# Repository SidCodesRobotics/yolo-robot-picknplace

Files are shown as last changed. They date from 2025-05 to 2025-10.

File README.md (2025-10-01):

# YOLOv8-Guided Mobile Robot with 5DOF Arm for Autonomous Waste Sorting 🤖






> 🎓 Final year project implementing an autonomous waste sorting robot using computer vision and robotics.

<p align="center">
MegaPi
</p>

## 📝 Table of Contents
- [About](#about)
- [Features](#features)
- [Architecture](#architecture)
- [Getting Started](#getting-started)
- [Current Limitations](#current-limitations)
- [Roadmap](#roadmap)
- [Contributing](#contributing)
- [Authors](#authors)
- [Acknowledgments](#acknowledgments)
- [License](#license)

## 🤔 About 

This project implements an autonomous waste sorting robot that combines computer vision, robotics, and machine learning. Using a YOLOv8n model for waste detection and ArUco markers for bin identification, the robot can identify, collect, and sort different types of waste materials.

📄 Our research paper can be found here: [Link to be added later]

### 🎯 Key Features 

- 🤖 Autonomous waste detection and sorting
- 🧠 Custom-trained YOLOv8n model (0.941 mAP@50)
- 🦾 5-DOF robotic arm for precise manipulation
- 🎯 ArUco marker-based bin detection
- 📱 Android app for remote control
- 🎛️ Dual microcontroller architecture
- 🔄 Real-time object detection

## 🏗️ Architecture 

### Hardware Stack
```
Robot/
│
├── Brain/
│   ├── Raspberry Pi 4 (8GB)
│   └── Arduino Mega 2560
│
├── Sensors/
│   ├── RPi Camera v2
│   ├── HC-SR04 Ultrasonic
│   └── HC-05 Bluetooth
│
├── Actuators/
│   ├── 3x MG996R Servos
│   ├── 3x SG90 Servos
│   └── 4x TT DC Motors
│
└── Controllers/
    ├── PCA9685 PWM Driver
    └── L293D Motor Driver
```

### Software Stack
```
Software/
│
├── Vision/
│   ├── YOLOv8n Custom Model
│   └── OpenCV (ArUco + Image Processing)
│
├── Control/
│   ├── Python High-level Control
│   └── Arduino C++ Low-level Control
│
└── Interface/
    └──  Android App
```

# Autonomous Waste Sorting Robot

## 🚀 Getting Started 

This is a final year project by Haouioui Sid Ahmed and Houhou Mohamed Dhia Eddine, focused on implementing an autonomous waste sorting robot using computer vision and robotics.

Our paper can be found here: [Link to be added]

---

### Hardware Requirements

Before you begin, ensure you have the following main **hardware components**:

* **Raspberry Pi 4 Model B** (8 GB RAM recommended): For computer vision and high-level control.
* **Arduino Mega 2560**: For motor control and low-level actuation tasks.
* **Robotic Arm**: A 5-DOF arm using SG90 and MG996R servo motors.
* **4-Wheeled Mobile Platform**: Driven by TT gear motors.
* **Raspberry Pi Camera Module v2**: Provides visual input for waste detection.
* **HC-SR04 Ultrasonic Sensor**: For distance measurement.
* **HC-05 Bluetooth Module**: For potential remote control and debugging.
* **Power Supply**:
    * A 7.4V 3000mAh LiPo battery pack for the Raspberry Pi.
    * Three 3.7V 2800mAh 18650 batteries for the Arduino and its components.
* **Motor Driver**: L293D Motor Driver Module for DC motors.
* **PWM Driver Board**: PCA9685 for controlling servo motors.
* **UART Connection**: Ensure proper wiring between the **Raspberry Pi (Serial /dev/ttyAMA0)** and **Arduino (Serial3)** for communication.

---

### Software Setup

#### 1. Arduino Code (`arduino_code.txt`)

This code controls the robot's physical movements, arm actuation, and communication with the Raspberry Pi via UART.

**Development Environment**:
Install the **Arduino IDE**.

**Libraries**:
You will need to install the following libraries within the Arduino IDE:
* `Wire.h`: For I2C communication.
* `Adafruit_PWMServoDriver.h`: For controlling the PCA9685 servo driver.
* `AFMotor.h`: For controlling the DC motors via the Adafruit Motor Shield (or L293D-based shield).

**Uploading the Code**:
1.  Open `arduino_code.txt` in the Arduino IDE.
2.  Select "**Arduino Mega 2560**" from `Tools` > `Board`.
3.  Select the correct serial port for your Arduino from `Tools` > `Port`.
4.  Upload the sketch to your Arduino Mega 2560.

#### 2. Raspberry Pi Code (`rpi_code.py`)

This Python script handles computer vision using YOLOv8n, object detection, bin identification, and sends commands to the Arduino.

**Operating System**:
Ensure your Raspberry Pi is running a compatible Linux OS (e.g., **Raspberry Pi OS**).

**Python Environment**:
The code is written in **Python 3**. Make sure Python 3 is installed.

**Libraries**:
Install the necessary Python libraries using pip:

```bash
pip install opencv-python time numpy pyserial imutils picamera2 ultralytics
```

## Project Overview

This project implements an autonomous waste sorting robot that combines computer vision, robotics, and machine learning to identify, collect, and sort different types of waste materials. The robot uses a YOLOv8n model for waste detection and ArUco markers for bin identification, all controlled through a Raspberry Pi 4 and Arduino Mega architecture.

### Key Features

- Autonomous waste detection and sorting
- Custom-trained YOLOv8n model for waste classification
- 5-DOF robotic arm for precise object manipulation
- ArUco marker-based bin detection system
- Android app for remote control and monitoring
- Dual microcontroller architecture (Raspberry Pi 4 + Arduino Mega)
- Real-time object detection and distance sensing

## System Architecture

### Hardware Components

- Raspberry Pi 4 (8GB) for high-level control and vision processing
- Arduino Mega 2560 for low-level hardware control
- Custom 3D printed chassis and robotic arm
- 6 servo motors (3x MG996R, 3x SG90) for arm control
- 4 TT DC motors for mobility
- Raspberry Pi Camera Module v2
- HC-SR04 ultrasonic sensor
- HC-05 Bluetooth module
- PCA9685 PWM driver for servo control
- L293D motor driver for DC motors

### Software Stack

- Custom YOLOv8n model for waste detection
- OpenCV for image processing and ArUco detection
- Python for high-level control
- Arduino C++ for low-level control
- Kotlin/Jetpack Compose for Android app
- Custom state machines for autonomous behavior

## Implementation Details

### Vision System
- Trained on a custom dataset from [Roboflow Universe](https://universe.roboflow.com/ai-project-i3wje/waste-detection-vqkjo/dataset/10)
- Detects three waste categories: metal, plastic, and paper
- Achieves 0.941 mAP@50 accuracy
- Real-time processing on Raspberry Pi 4

### Robotic Arm
The 5-DOF robotic arm is based on the design from [OmArTronics](https://omartronics.com/diy-6-dof-robotic-arm-with-bluetooth-control-design-build-and-program/), modified and optimized for our specific use case. It features:
- 5 degrees of freedom for complex manipulation
- Custom-designed 3D printed components
- Precision servo control through PCA9685
- Pre-programmed movement sequences for reliable operation

### Mobile Application
An Android application (MegaPi APP) provides:
- Manual and autonomous mode control
- Real-time status monitoring
- Speed control in manual mode
- Bluetooth connectivity

## Demonstration

See our robot in action: [YouTube Demo](https://youtu.be/VdJLIz-9X8A)

## ⚠️ Current Limitations 

### Robotic Arm and Manipulation
- [ ] Fixed movement patterns using pre-set positions
- [ ] Limited adaptability to object variations
- [ ] No real-time position feedback

### Locomotion and Chassis
- [ ] No encoder feedback for precise movement
- [ ] Timer-based turning (accuracy issues)

### Perception and Sensing
- [ ] Not that relaiable ultrasonic readings
- [ ] Limited 2D vision (no depth perception)
- [ ] ArUco marker dependency for bin detection
- [ ] Limited field of view (no environment scanning)

### Performance
- [ ] Slow object detection (~1 FPS on RPi4) / not obtimized enough
- [ ] Occasional misclassifications
- [ ] Basic state machine architecture
- [ ] Limited Bluetooth range/speed (HC-05)

### Power Management
- [ ] Dual power source complexity
- [ ] No battery monitoring system
- [ ] No low power handling

## 🛣️ Roadmap 
A roadmap for contributors, students, or hobbyists who may want to extend the system and make it more robust.

# Q&A (Roadmap for Improvements)

This section highlights common questions about the project and outlines possible improvements.  
The goal is not to present a final product, but to provide a roadmap for making the system more robust and capable.

---

### Q1. The robotic arm currently uses pre-set positions. Is this enough?

**A1:**  
Pre-set positions are sufficient for a demo or proof of concept, but they limit flexibility.  
Next steps for improvement include:  
- Adding **inverse kinematics (IK)** so the arm can move to any target position dynamically.  
- Using **servo feedback or smart servos** for better precision.  

This would make the robot better at adapting to objects in different positions.

---

### Q2. The project uses only a 2D Pi Camera. Should we add depth sensing?

**A2:**  
A 2D camera works for testing, but without depth perception the robot has trouble estimating distances.  
Improvements:  
- Add a **depth camera** (e.g., Intel RealSense, Orbbec).  
- Or combine the Pi Camera with **distance sensors**.  

This would enable more accurate 3D localization of objects.

---

### Q3. The YOLOv8 model sometimes misclassifies objects. How can detection be improved?

**A3:**  
Ways to improve detection accuracy:  
- Collect more training data from varied environments.  
- Run the model on faster hardware (Coral TPU, Jetson Nano).  

These steps would make classification more consistent and reliable.

---

### Q4. Bin detection relies on ArUco markers. Can this be improved?

**A4:**  
ArUco markers are useful for testing but not practical long term.  
Future improvements:  
- Train the system to recognize bins by **shape or color**.  

This would reduce reliance on artificial markers and make the system more flexible.

---

### Q5. Navigation is timer-based. What would be a better approach?

**A5:**  
- Adding **wheel encoders** for closed-loop control.  
- Implementing **basic SLAM** using a camera or depth sensor.  
- Adding **bump sensors** as a safety mechanism.  

This would make movement more precise.

---

### Q6. Ultrasonic sensors are noisy. Should we replace them?

**A6:**  
Ultrasonic sensors are fine for experiments but it's inconsistent.  
- Switching to **ToF sensors** (VL53L0X).  
- Using a **depth camera** for obstacle detection.  
- Keeping bump sensors as a backup.  

This would provide more reliable perception.

---

### Q7. The arm struggles with heavier objects. How can we improve strength?

**A7:**  
For light demos, hobby servos are fine, but improvements include:  
- Replace SG90 servos with **metal-gear, higher-torque models**.  
- Add **overcurrent protection** to prevent burnout.  
- Use stronger frame materials (aluminum, reinforced plastic).  

This would make the arm more durable.

---

### Q8. The robot depends on a mobile app for control. Should it be more autonomous?

**A8:**  
Yes. The app is useful for testing, but autonomy should be the next step:  

---

### Q9. The project uses multiple separate batteries. Is there a better approach?

**A9:**  
Yes. For simplicity and reliability:  
- Use a **single Li-ion pack** with a Battery Management System (BMS).  
- Add **voltage monitoring** for safe shutdown.  
- Design a **docking/charging system**.  

This reduces wiring complexity and improves stability.

---

### Q10. How can safety be improved?

**A10:**  
Safety matters even in research projects. Improvements include:  
- Add **force limits** for the arm.  
- Include **collision detection** via current sensing.  
- Implement an **emergency stop button**.  

This ensures safe testing and development.

---

### Q11. What if someone wants to build on this project further?

**A11:**  
Future directions could include:  
- Transitioning to **ROS/ROS2** for scalability.  

## ✍️ Authors 

- [@Haouioui Sid Ahmed](mailto:haouiouiahmed0@gmail.com)
- [@Houhou Mohamed Dhia Eddine](mailto:Dhayoohouhou@gmail.com)

## 🎉 Acknowledgments 

- Dr. Terki Nadjiba - Project Supervisor
- [OmArTronics](https://omartronics.com/diy-6-dof-robotic-arm-with-bluetooth-control-design-build-and-program/) - Robotic Arm Design
- [Roboflow Universe](https://universe.roboflow.com/ai-project-i3wje/waste-detection-vqkjo/dataset/10) - Dataset

## 📝 License 

This project is licensed under the Creative Commons Attribution-NonCommercial-ShareAlike 4.0 International License (CC BY-NC-SA 4.0).

### Terms
- ✅ Share and Adapt
- ❌ No Commercial Use
- 📝 Must Give Credit
- 🔄 Share Under Same License

For more details, see the [full license text](https://creativecommons.org/licenses/by-nc-sa/4.0/legalcode).

### Citation
```bibtex
@misc{yolov8_waste_sorting_robot,
  title={YOLOv8-Guided Mobile Robot with 5DOF Arm for Autonomous Waste Sorting},
  author={Haouioui, Sid Ahmed and Houhou, Mohamed Dhia Eddine},
  year={2025},
  publisher={GitHub},
  howpublished={\url{https://github.com/SidCodesRobotics/yolo-robot-picknplace}}
}
```

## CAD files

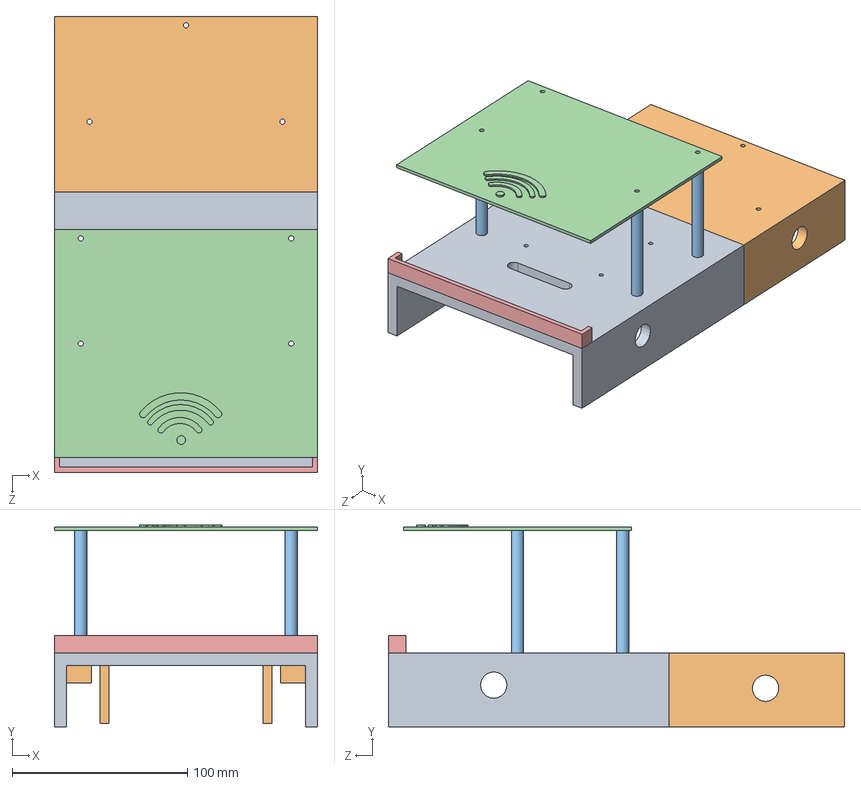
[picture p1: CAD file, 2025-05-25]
design/mobile robot/Assem2.SLDASM
150.0 x 115.0 x 260.0 mm

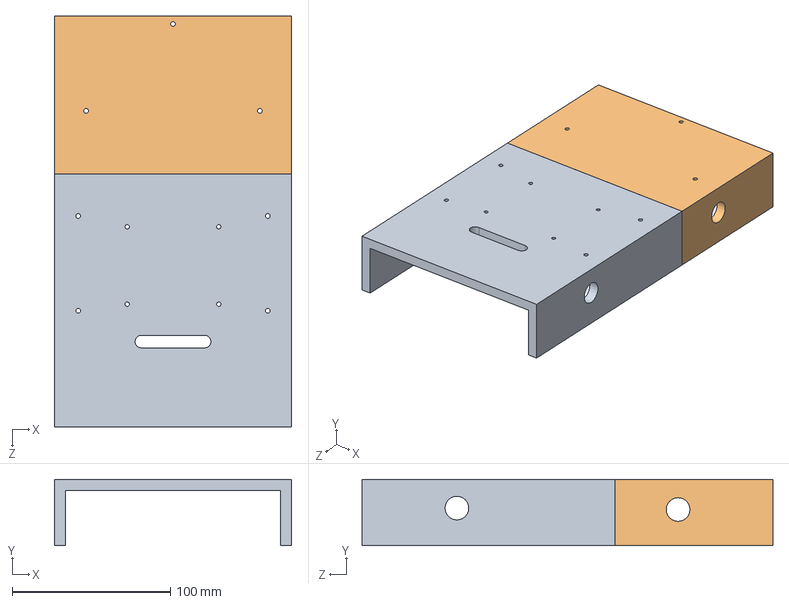
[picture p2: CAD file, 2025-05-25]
design/mobile robot/Assem1.SLDASM
150.0 x 42.0 x 260.0 mm

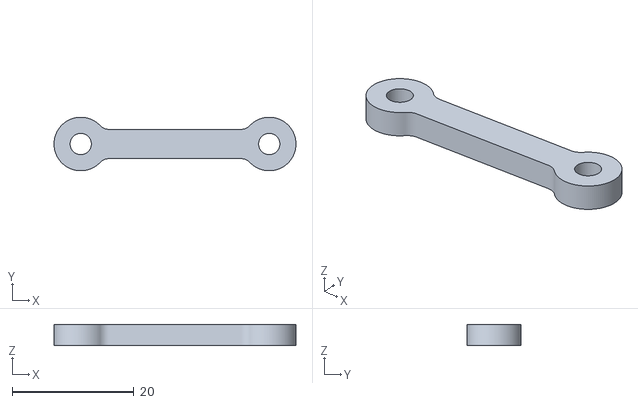
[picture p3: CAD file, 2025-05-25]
design/arm/6-DOF Robotic Arm with Centralization Ring/gripper_link.stl
39.8 x 8.80 x 3.50

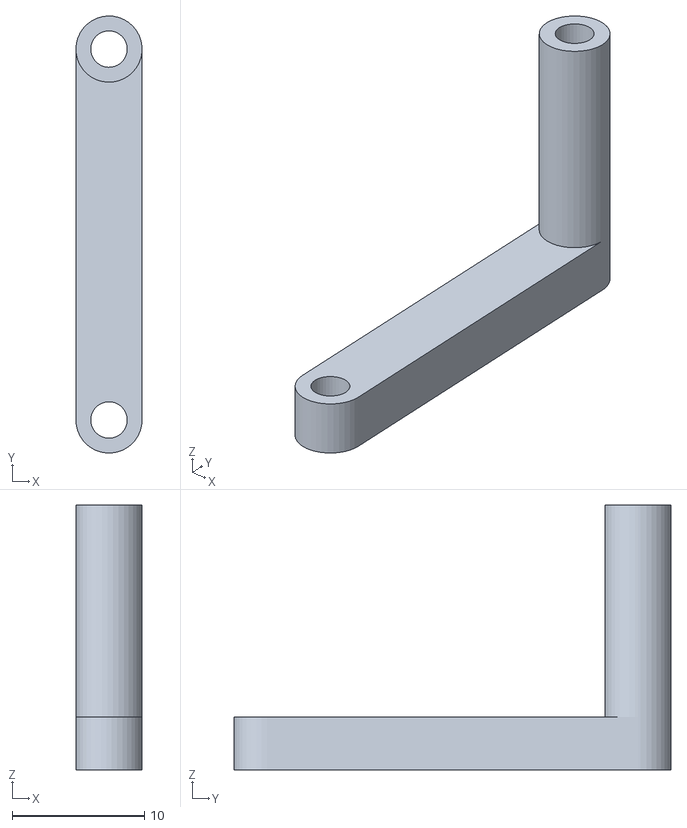
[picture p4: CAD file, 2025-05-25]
design/mobile robot design with wheels coupler/shield driver1.STL
5.00 x 33.0 x 20.0

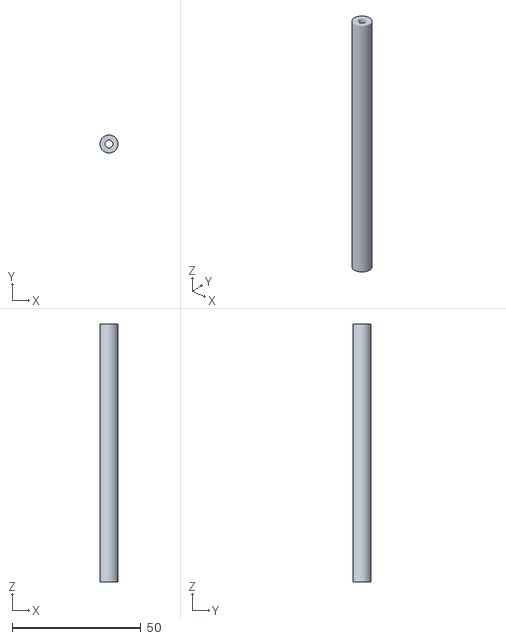
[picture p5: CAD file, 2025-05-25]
design/mobile robot design without wheels coupler/platform support.STL
7.00 x 6.99 x 100.0

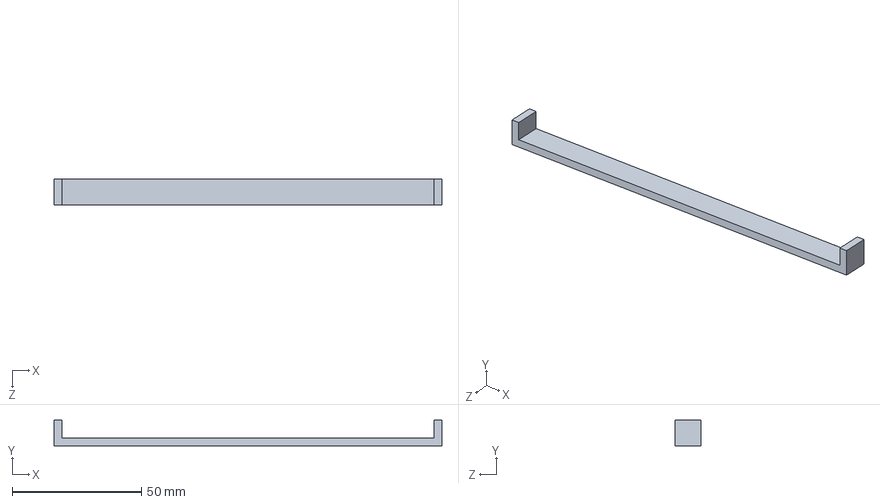
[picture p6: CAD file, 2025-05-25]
design/mobile robot/Part9.SLDPRT
150.0 x 10.0 x 10.0 mm

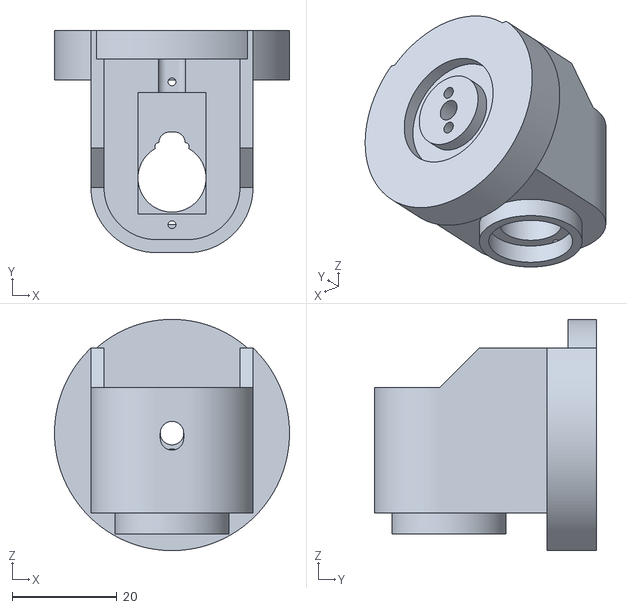
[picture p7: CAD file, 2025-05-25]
design/arm/6-DOF Robotic Arm with Centralization Ring/arm_link_3.stl
44.9 x 42.5 x 44.2

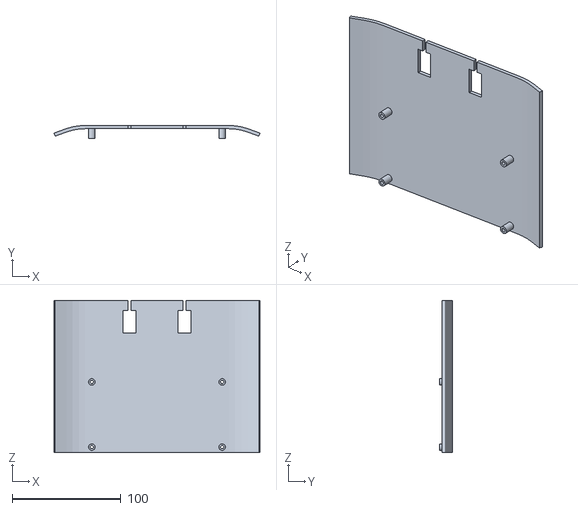
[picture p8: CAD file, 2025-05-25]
design/mobile robot design with wheels coupler/cover.STL
189.6 x 12.0 x 140.0

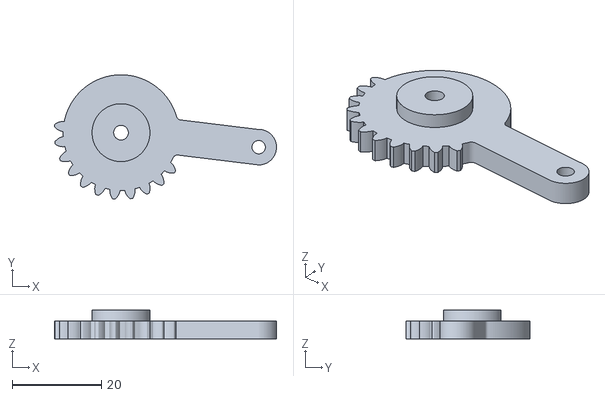
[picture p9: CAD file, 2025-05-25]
design/arm/6-DOF Robotic Arm with Centralization Ring/gripper_gear_right.stl
49.9 x 27.9 x 6.50

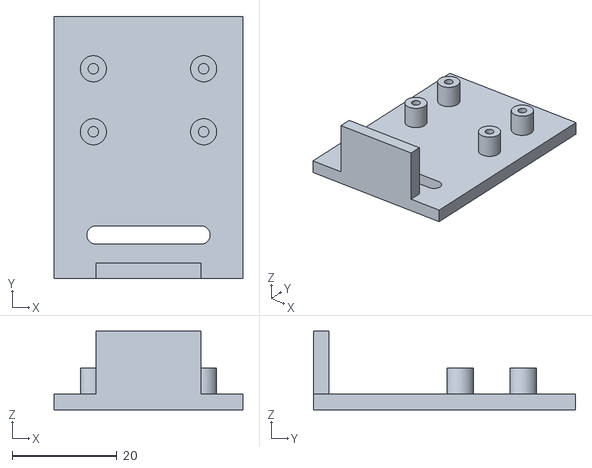
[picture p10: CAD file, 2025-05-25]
design/mobile robot design with wheels coupler/cam.STL
36.0 x 50.0 x 15.0

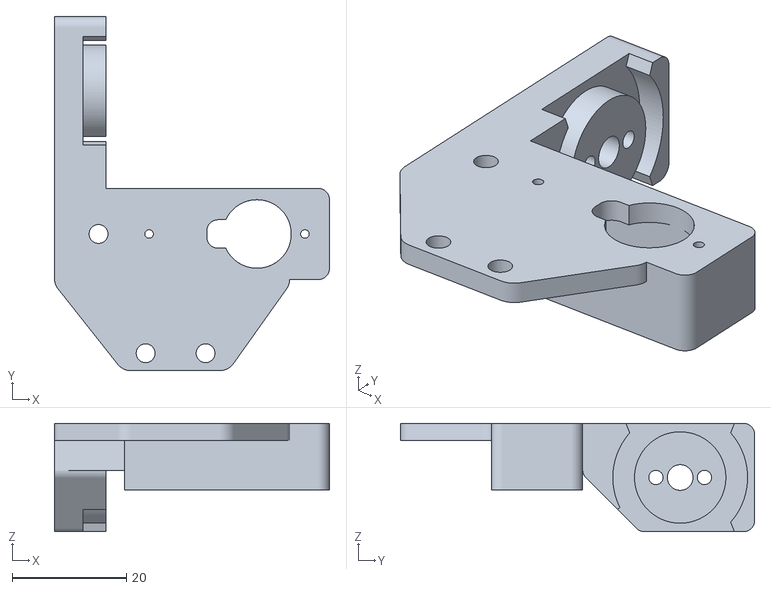
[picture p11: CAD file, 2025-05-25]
design/arm/6-DOF Robotic Arm with Centralization Ring/gripper_base.stl
48.2 x 62.1 x 19.0

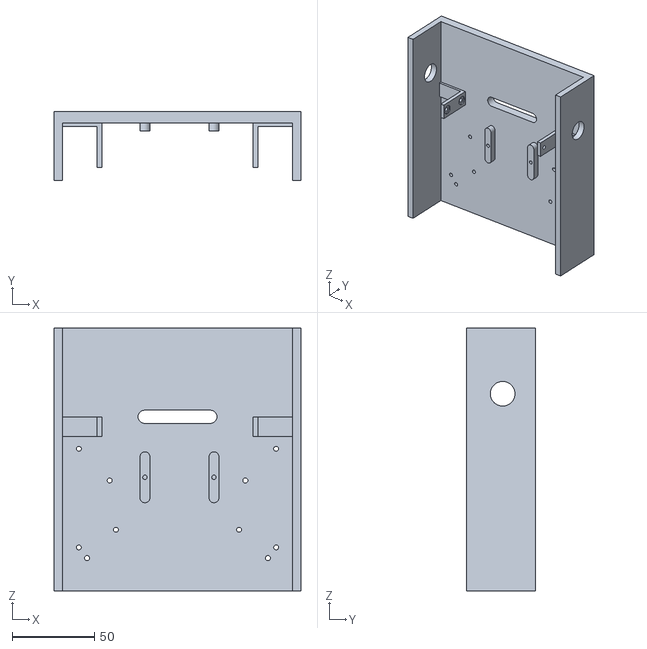
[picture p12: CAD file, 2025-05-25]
design/mobile robot design with wheels coupler/base2.STL
150.0 x 42.0 x 160.0

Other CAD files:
design/mobile robot/platform support.SLDPRT
design/mobile robot/shield driver1.SLDPRT
design/mobile robot/cam.SLDPRT
design/arm/6-DOF Robotic Arm with Centralization Ring/arm_link_1.stl
design/arm/6-DOF Robotic Arm with Centralization Ring/arm_link_2.stl
design/arm/6-DOF Robotic Arm with Centralization Ring/base_link.stl
design/arm/6-DOF Robotic Arm with Centralization Ring/base_link_upper.stl
design/arm/6-DOF Robotic Arm with Centralization Ring/gripper_gear_left.stl
design/arm/6-DOF Robotic Arm with Centralization Ring/gripper_part_left.stl
design/arm/6-DOF Robotic Arm with Centralization Ring/gripper_part_right.stl
design/arm/6-DOF Robotic Arm with Centralization Ring/gripper_sleeve.stl
design/mobile robot design with wheels coupler/arduino support.STL
design/mobile robot design with wheels coupler/base1.STL
design/mobile robot design with wheels coupler/battery support.STL
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

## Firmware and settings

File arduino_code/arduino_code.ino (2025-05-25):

/*
 * Hey there! This is our Arduino code for the waste sorting robot.
 * It handles all the robot movement, arm control, Bluetooth stuff,
 * and talks to the Raspberry Pi using UART. Basically the brains of 
 * the operation for motor control and physical actions.
 * 
 * We've kept the architecture pretty simple by unifying our approach
 * for both objects and bins - makes the code way cleaner!
 */

#include <Wire.h>
#include <Adafruit_PWMServoDriver.h>
#include <AFMotor.h>

// Initialize motors using Adafruit Motor Shield
AF_DCMotor motor1(1);
AF_DCMotor motor2(2);
AF_DCMotor motor3(3);
AF_DCMotor motor4(4);

// Ultrasonic sensor pins
#define TRIG_PIN 22
#define ECHO_PIN 23

// Servo channel setup - these are the PWM channels on the driver board
#define SERVO_FREQ 50 // Standard 50Hz for RC servos
#define BASE_CHANNEL 0
#define SHOULDER_CHANNEL 4
#define ELBOW_CHANNEL 8
#define WRIST_ROT_CHANNEL 10
#define WRIST_UD_CHANNEL 15
#define GRIPPER_CHANNEL 14

// Arm positions for different actions - these took FOREVER to calibrate!
#define SCAN_BASE 55
#define SCAN_SHOULDER 60
#define SCAN_ELBOW 100
#define SCAN_WRIST_ROT 80
#define SCAN_WRIST_UD 25
#define SCAN_GRIPPER 120

#define PICKUP_BASE 55
#define PICKUP_SHOULDER 23
#define PICKUP_ELBOW 90
#define PICKUP_WRIST_ROT 80
#define PICKUP_WRIST_UD 25
#define PICKUP_GRIPPER 10

#define CARRY_BASE 55
#define CARRY_SHOULDER 60
#define CARRY_ELBOW 100
#define CARRY_WRIST_ROT 80
#define CARRY_WRIST_UD 10
#define CARRY_GRIPPER 10

#define DROPOFF_BASE 55
#define DROPOFF_SHOULDER 60
#define DROPOFF_ELBOW 75
#define DROPOFF_WRIST_ROT 80
#define DROPOFF_WRIST_UD 25
#define DROPOFF_GRIPPER 120

// Special position for going forward after finding the bin with camera
#define FORWARD_ELBOW 75

// Some important constants we figured out through testing
#define DEFAULT_SPEED 200
#define TURN_MS_PER_DEGREE 4.3  // Roughly 4.3ms per degree at speed 200
#define MIN_DISTANCE 7  // Too close! Emergency stop at 7cm
#define OBJECT_STOP_DISTANCE 18.0 // Sweet spot for grabbing objects
#define BIN_STOP_DISTANCE 11.0 // Sweet spot for dropping in bins

// Create servo driver object
Adafruit_PWMServoDriver servoDriver = Adafruit_PWMServoDriver();

// --- State Machine Stuff ---
// Operating modes - either manual control or autonomous
enum Mode {
  MANUAL,
  AUTO
};

// What we're currently targeting - either an object to pick up or a bin to drop in
enum Target {
  OBJECT,
  BIN_TARGET
};

// Our robot's brain states - what it's currently doing
enum RobotState {
  IDLE,         // Just chilling, waiting for commands
  SEARCH,       // Looking around for something interesting
  ALIGN_ROUGH,  // Found something! Turning roughly towards it
  ALIGN_FINE,   // Fine-tuning our alignment (camera helps here)
  APPROACH,     // Moving forward until we're close enough
  ACTION,       // Doing the pickup or dropoff
  TRANSITION,   // Switching between targets
  COMPLETE      // All done, mission accomplished!
};

// Global variables
Mode currentMode = MANUAL;
Target currentTarget = OBJECT;
RobotState currentState = IDLE;
RobotState lastReportedState = IDLE;  // For debugging

boolean waitingForRPiResponse = false;
unsigned long lastCommandTime = 0;
unsigned long lastStatusMessageTime = 0; // For throttling app messages
int manualSpeed = 150;  // Default manual speed (medium)

// Initialize static variables for state tracking
boolean actionCompleted = false;  // Flag for tracking action completion

void setup() {
  // Initialize serial communications
  Serial.begin(115200);    // Debug serial
  Serial1.begin(9600);     // Bluetooth serial
  Serial3.begin(115200);   // UART to Raspberry Pi
  
  // Initialize ultrasonic sensor pins
  pinMode(TRIG_PIN, OUTPUT);
  pinMode(ECHO_PIN, INPUT);
  
  // Initialize servo driver
  servoDriver.begin();
  servoDriver.setOscillatorFrequency(25000000);
  servoDriver.setPWMFreq(SERVO_FREQ);
  
  // Set initial motor speeds
  motor1.setSpeed(manualSpeed);
  motor2.setSpeed(manualSpeed);
  motor3.setSpeed(manualSpeed);
  motor4.setSpeed(manualSpeed);
  
  // Set arm to initial position
  moveArmToScanPosition();
  
  // Stop all motors initially
  stopMotors();
  
  Serial.println("Arduino initialized. Ready for commands.");
  Serial1.println("System ready");
}

void loop() {
  // Check for Bluetooth commands from the app
  if (Serial1.available() > 0) {
    char command = Serial1.read();
    processBluetoothCommand(command);
  }
  
  // Check for commands from Raspberry Pi
  if (Serial3.available() > 0) {
    String command = Serial3.readStringUntil('\n');
    processRaspberryPiCommand(command);
  }
  
  // Check for Serial monitor debug commands
  if (Serial.available() > 0) {
    processSerialDebugCommand();
  }
  
  // Always send status messages to app in AUTO mode
  if (currentMode == AUTO) {
    sendStatusMessage();
    
    // Print debug distance info every second
    static unsigned long lastDebugTime = 0;
    if (millis() - lastDebugTime > 1000) {
      float distance = getDistance();
      String targetName = (currentTarget == OBJECT) ? "OBJECT" : "BIN";
      String stateName = getStateName(currentState);
      Serial.println("DEBUG - Distance: " + String(distance) + " cm, Target: " + targetName + ", State: " + stateName);
      lastDebugTime = millis();
    }
  }
  
  // Execute auto mode state machine when not waiting for RPi
  if (currentMode == AUTO && !waitingForRPiResponse) {
    executeAutoMode();
  }
}

// Process commands from the bluetooth app
void processBluetoothCommand(char command) {
  if (command == 'A') {
    // Activate Auto Mode
    if (currentMode == MANUAL) {
      activateAutoMode();
    }
  } else if (command == 'O') {
    // Deactivate Auto Mode
    if (currentMode == AUTO) {
      deactivateAutoMode();
    }
  } else if (currentMode == MANUAL) {
    // Handle manual mode movement commands
    processManualMovementCommand(command);
  }
}

void activateAutoMode() {
  currentMode = AUTO;
  currentTarget = OBJECT;
  currentState = SEARCH;
  Serial.println("Activating Auto Mode - Target: OBJECT, State: SEARCH");
  
  // Clear any pending messages
  while (Serial1.available()) Serial1.read();
  
  // Signal app and RPi
  Serial1.println("AUTO_START?");
  delay(400);
  Serial3.println("AUTO_START");
  
  // Move arm to scan position
  moveArmToScanPosition();
}

void deactivateAutoMode() {
  currentMode = MANUAL;
  stopMotors();
  Serial.println("Deactivating Auto Mode");
  
  // Clear any pending messages
  while (Serial1.available()) Serial1.read();
  
  // Signal app and RPi
  Serial1.println("MANUAL_MODE?");
  delay(400);
  Serial3.println("AUTO_STOP");
}

void processManualMovementCommand(char command) {
  switch (command) {
    case 'G': // Forward
      moveForward(manualSpeed);
      break;
    case 'H': // Backward
      moveBackward(manualSpeed);
      break;
    case 'I': // Left
      turnLeft(manualSpeed);
      break;
    case 'J': // Right
      turnRight(manualSpeed);
      break;
    case 'K': // Stop
      stopMotors();
      break;
    // Speed control commands
    case 'Z': // High speed
      manualSpeed = 255;
      updateRunningMotorSpeeds(manualSpeed);
      break;
    case 'Y': // Medium speed
      manualSpeed = 150;
      updateRunningMotorSpeeds(manualSpeed);
      break;
    case 'X': // Low speed
      manualSpeed = 100;
      updateRunningMotorSpeeds(manualSpeed);
      break;
  }
}

void processSerialDebugCommand() {
  char input = Serial.read();
  if (input == 'N' || input == 'n') {
    // Send NEXT_STATE command to RPi
    Serial.println("Manual state advancement requested");
    Serial3.println("NEXT_STATE");
  } else if (input == 'D' || input == 'd') {
    // Force a distance measurement
    float distance = getDistance();
    Serial.println("Manual distance check: " + String(distance) + " cm");
  } else if (input == 'S' || input == 's') {
    // Emergency stop
    stopMotors();
    Serial.println("EMERGENCY STOP from serial monitor");
  } else if (input == 'O' || input == 'o') {
    // Force transition to OBJECT target
    currentTarget = OBJECT;
    currentState = SEARCH;
    Serial.println("Forced target change to OBJECT");
  } else if (input == 'B' || input == 'b') {
    // Force transition to BIN target
    currentTarget = BIN_TARGET;
    currentState = SEARCH;
    Serial.println("Forced target change to BIN");
  }
}

// Process commands from the Raspberry Pi
void processRaspberryPiCommand(String command) {
  Serial.println("Received from RPi: " + command);
  
  if (command.startsWith("TURN:")) {
    // Format: TURN:angle (positive = right, negative = left)
    int angle = command.substring(5).toInt();
    executeTurn(angle);
    Serial3.println("TURN_COMPLETE");
    // After completing the turn, if in ALIGN states, move directly to APPROACH
    if (currentState == ALIGN_ROUGH || currentState == ALIGN_FINE) {
      Serial3.println("DETECTION_LOCK"); // Tell RPi to stop aruco detection
      Serial.println("Alignment complete, locking detection");
      delay(300); // Increased delay to ensure lock command is processed
      Serial3.println("DETECTION_LOCK"); // Send twice to be extra sure
      // Add a short delay before starting approach
      delay(500);
      
      // Set elbow to forward position before moving forward
      moveServo(ELBOW_CHANNEL, FORWARD_ELBOW);
      
      // Auto-start approach after alignment is done
      currentState = APPROACH;
      moveForward(DEFAULT_SPEED);
      Serial3.println("APPROACH_STARTED");
      // Send detection lock one more time after approach started
      delay(200);
      Serial3.println("DETECTION_LOCK");
    }
    waitingForRPiResponse = false;
  } 
  else if (command == "APPROACH") {
    // Start approaching the current target
    Serial.println("Starting approach toward " + String(currentTarget == OBJECT ? "OBJECT" : "BIN"));
    
    // Set elbow to 60 degrees position before moving forward if approaching after ArUco alignment
    if (currentTarget == BIN_TARGET) {
      moveServo(ELBOW_CHANNEL, FORWARD_ELBOW);
      
      // Ensure we disable detection completely
      Serial3.println("DETECTION_LOCK");
      delay(200); // Small delay to ensure command is processed
      Serial3.println("DETECTION_LOCK"); // Send twice to be extra sure
    }
    
    currentState = APPROACH;
    moveForward(DEFAULT_SPEED);
    // Tell RPi we're in approach mode, don't send further aruco detections
    Serial3.println("APPROACH_STARTED");
    Serial3.println("DETECTION_LOCK");
    waitingForRPiResponse = false;
  }
  else if (command == "STOP") {
    stopMotors();
    Serial3.println("STOP_COMPLETE");
    waitingForRPiResponse = false;
  }
  else if (command == "PICKUP") {
    performPickup();
    waitingForRPiResponse = false;
  }
  else if (command == "DROPOFF") {
    // Immediately execute dropoff when commanded
    performDropoff();
    waitingForRPiResponse = false;
  }
  else if (command == "SWITCH_TO_BIN") {
    // Switch target from OBJECT to BIN
    currentTarget = BIN_TARGET;
    currentState = SEARCH;
    Serial.println("Switching target to BIN, state to SEARCH");
    Serial3.println("TARGET_SWITCHED_TO_BIN");
    waitingForRPiResponse = false;
  }
  else if (command == "BACKWARD") {
    moveBackward(DEFAULT_SPEED);
    delay(1500);
    stopMotors();
    Serial3.println("BACKWARD_COMPLETE");
    waitingForRPiResponse = false;
  }
  else if (command == "DETECTION_LOCK") {
    // Explicit acknowledgment of detection lock command
    Serial.println("Acknowledging detection lock");
    Serial3.println("DETECTION_LOCK_ACKNOWLEDGED");
    waitingForRPiResponse = false;
  }
  else if (command.startsWith("SPEED:")) {
    // Format: SPEED:value (0-255)
    int speedValue = command.substring(6).toInt();
    if (speedValue >= 0 && speedValue <= 255) {
      setMotorSpeeds(speedValue);
      Serial3.println("SPEED_SET");
    } else {
      Serial3.println("INVALID_SPEED");
    }
    waitingForRPiResponse = false;
  }
  else if (command == "DISTANCE") {
    float distance = getDistance();
    Serial3.println("Distance: " + String(distance) + " cm");
    waitingForRPiResponse = false;
  }
  else if (command == "SCAN") {
    moveArmToScanPosition();
    Serial3.println("SCAN_COMPLETE");
    waitingForRPiResponse = false;
  }
  else if (command == "CARRY") {
    moveArmToCarryPosition();
    Serial3.println("CARRY_COMPLETE");
    waitingForRPiResponse = false;
  }
  else if (command == "NEXT_STATE") {
    // For debugging
    waitingForRPiResponse = false;
  }
  else {
    // Unknown command
    Serial.println("Unknown command: " + command);
    waitingForRPiResponse = false;
  }
}

// Where the magic happens for the autonomous mode
void executeAutoMode() {
  // Keep track of the previous state so we can detect transitions
  RobotState previousState = lastReportedState;
  
  // Let everyone know when we're changing states
  reportStateChange();
  
  // Special case when we're moving from alignment to approach mode
  if ((previousState == ALIGN_ROUGH || previousState == ALIGN_FINE) && currentState == APPROACH) {
    if (currentTarget == BIN_TARGET) {
      // Need to adjust the arm position before driving forward
      moveServo(ELBOW_CHANNEL, FORWARD_ELBOW);
      Serial.println("ArUco alignment complete - set elbow to forward position (60°)");
    }
  }
  
  switch (currentState) {
    case SEARCH:
      // The Pi is looking for stuff, we just wait patiently
      waitingForRPiResponse = true;
      break;
      
    case ALIGN_ROUGH:
    case ALIGN_FINE:
      // Let the Pi do its computer vision magic and tell us where to turn
      waitingForRPiResponse = true;
      break;
      
    case APPROACH:
      // This is where we actually drive forward until we're close enough
      executeApproach();
      break;
      
    case ACTION:
      // We already did the action in the transition, just waiting now
      waitingForRPiResponse = true;
      break;
      
    case TRANSITION:
      // Time to switch between tasks
      if (currentTarget == OBJECT && !actionCompleted) {
        // We just grabbed something, now let's find a bin for it
        currentTarget = BIN_TARGET;
        currentState = SEARCH;
        actionCompleted = true;
        Serial.println("Transitioning to BIN search");
        
        // Tell the Pi we're ready to look for bins now
        Serial3.println("READY_FOR_BIN_SEARCH");
      }
      else {
        // We're all done!
        currentState = COMPLETE;
      }
      break;
      
    case COMPLETE:
      // Victory lap - we've completed the task
      if (!actionCompleted) {
        Serial.println("Task complete!");
        Serial3.println("TASK_COMPLETE");
        actionCompleted = true;
      }
      break;
      
    default:
      break;
  }
}

// Moving toward our target until we're close enough
void executeApproach() {
  float distance = getDistance();
  
  // Different targets need different stopping distances
  float stopDistance = (currentTarget == OBJECT) ? OBJECT_STOP_DISTANCE : BIN_STOP_DISTANCE;
  
  // Keep us updated on how things are going
  String targetType = (currentTarget == OBJECT) ? "OBJECT" : "BIN";
  Serial.println("Approach " + targetType + " - distance: " + String(distance) + 
                " cm, stop at: " + String(stopDistance) + " cm");
  
  // Let the Pi know our current distance
  Serial3.println("Distance: " + String(distance) + " cm");
  
  // Safety first! Emergency stop if we're WAY too close
  if (distance <= MIN_DISTANCE) {
    stopMotors();
    Serial.println("EMERGENCY STOP - Too close! Distance: " + String(distance) + " cm");
    
    // If we had to emergency stop at a bin, try to recover by dropping off anyway
    if (currentTarget == BIN_TARGET) {
      Serial.println("Forcing bin reached notification due to emergency stop");
      Serial3.println("BIN_DISTANCE_REACHED");
      performDropoff();
    }
    return;
  }
  
  if (distance <= stopDistance) {
    // Stop motors when target distance reached
    stopMotors();
    Serial.println("TARGET REACHED: " + String(distance) + " cm");
    
    // Print additional details for debugging
    String msg = (currentTarget == OBJECT) ? 
                "Object reached - executing pickup" : 
                "Bin reached - executing dropoff";
    Serial.println(msg);
    
    // Send appropriate notification to RPi
    if (currentTarget == OBJECT) {
      Serial3.println("TARGET_DISTANCE_REACHED");
      // Auto-execute pickup sequence
      performPickup();
    } else { // BIN_TARGET
      Serial3.println("BIN_DISTANCE_REACHED");
      // Auto-execute dropoff immediately
      performDropoff();
      // currentState is set to TRANSITION within performDropoff()
    }
  }
  else if (distance <= (stopDistance + 5.0)) {
    // When very close to the target, move very slowly with careful distance checks
    int slowSpeed = 50;  // Very slow approach speed
    setMotorSpeeds(slowSpeed);
    Serial.println("Final approach - very slow speed: " + String(slowSpeed));
  }
  else {
    // Adjust speed based on distance
    adjustSpeedBasedOnDistance(distance, stopDistance);
  }
}

// Fancy distance-based speed control to make smoother approaches
void adjustSpeedBasedOnDistance(float distance, float stopDistance) {
  int speed;
  
  // Bins need extra careful approach - don't want to crash into them!
  if (currentTarget == BIN_TARGET) {
    // Slow down more aggressively as we get closer to the bin
    if (distance < 20) {
      // Creeping forward soooo slowly
      speed = 60;
    }
    else if (distance < 30) {
      // Pretty close, take it easy
      speed = 80;
    }
    else if (distance <= 50) {
      // Getting there, moderate pace
      speed = 120;
    }
    else {
      // Still far away, let's make some progress
      speed = 150;
    }
  } else {
    // Objects are a bit more forgiving for approach
    if (distance < 35) {
      // Getting close, slow down
      speed = 85;
    }
    else if (distance <= 50) {
      // Medium distance, steady pace
      speed = 100;
    }
    else {
      // Still far away, let's go faster
      speed = 150;
    }
  }
  
  // Update all motors to the new speed
  setMotorSpeeds(speed);
  
  // Only log when the speed actually changes to avoid spamming
  static int lastSpeed = 0;
  if (speed != lastSpeed) {
    Serial.println("Adjusting speed to " + String(speed) + " at distance " + String(distance) + " cm");
    lastSpeed = speed;
  }
}

// Perform complete pickup sequence
void performPickup() {
  Serial.println("Executing pickup sequence");
  
  // Stop motors if still moving
  stopMotors();
  
  // Move arm to pickup position
  moveArmToPickupPosition();
  Serial.println("Pickup complete");
  Serial3.println("PICKUP_COMPLETE");
  
  // Wait a moment to stabilize
  delay(1000);
  
  // Move arm to carry position
  moveArmToCarryPosition();
  Serial.println("Object in carry position");
  Serial3.println("CARRY_COMPLETE");
  
  // Transition to next phase
  currentState = TRANSITION;
  actionCompleted = false;
}

// Perform dropoff sequence
void performDropoff() {
  Serial.println("Executing dropoff sequence immediately");
  
  // Stop motors if still moving
  stopMotors();
  
  // Move arm to dropoff position
  moveArmToDropoffPosition();
  Serial.println("Dropoff complete");
  Serial3.println("DROPOFF_COMPLETE");
  
  // Transition to complete
  currentState = TRANSITION;
  actionCompleted = false;
}

// Motor control functions
void moveForward(int speed) {
  setMotorSpeeds(speed);
  motor1.run(FORWARD);
  motor2.run(FORWARD);
  motor3.run(FORWARD);
  motor4.run(FORWARD);
}

void moveBackward(int speed) {
  setMotorSpeeds(speed);
  motor1.run(BACKWARD);
  motor2.run(BACKWARD);
  motor3.run(BACKWARD);
  motor4.run(BACKWARD);
}

void turnLeft(int speed) {
  setMotorSpeeds(speed);
  motor1.run(BACKWARD);
  motor2.run(BACKWARD);
  motor3.run(FORWARD);
  motor4.run(FORWARD);
}

void turnRight(int speed) {
  setMotorSpeeds(speed);
  motor1.run(FORWARD);
  motor2.run(FORWARD);
  motor3.run(BACKWARD);
  motor4.run(BACKWARD);
}

void stopMotors() {
  motor1.run(RELEASE);
  motor2.run(RELEASE);
  motor3.run(RELEASE);
  motor4.run(RELEASE);
}

void setMotorSpeeds(int speed) {
  motor1.setSpeed(speed);
  motor2.setSpeed(speed);
  motor3.setSpeed(speed);
  motor4.setSpeed(speed);
}

void executeTurn(int angle) {
  // Positive angle = turn right, negative angle = turn left
  unsigned long turnTime = abs(angle) * TURN_MS_PER_DEGREE;
  
  Serial.println("Turning " + String(angle) + " degrees, time: " + String(turnTime) + "ms");
  
  if (angle > 0) {
    turnRight(DEFAULT_SPEED);
  } else {
    turnLeft(DEFAULT_SPEED);
  }
  
  delay(turnTime);
  stopMotors();
  Serial.println("Turn completed");
  delay(1000);  // Small pause after turn
}

// Update motor speeds without changing direction
void updateRunningMotorSpeeds(int speed) {
  setMotorSpeeds(speed);
}
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
